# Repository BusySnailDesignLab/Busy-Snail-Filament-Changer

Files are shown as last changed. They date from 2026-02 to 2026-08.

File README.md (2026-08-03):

# Busy Snail Filament Changer<sup>*</sup> (BSFC)

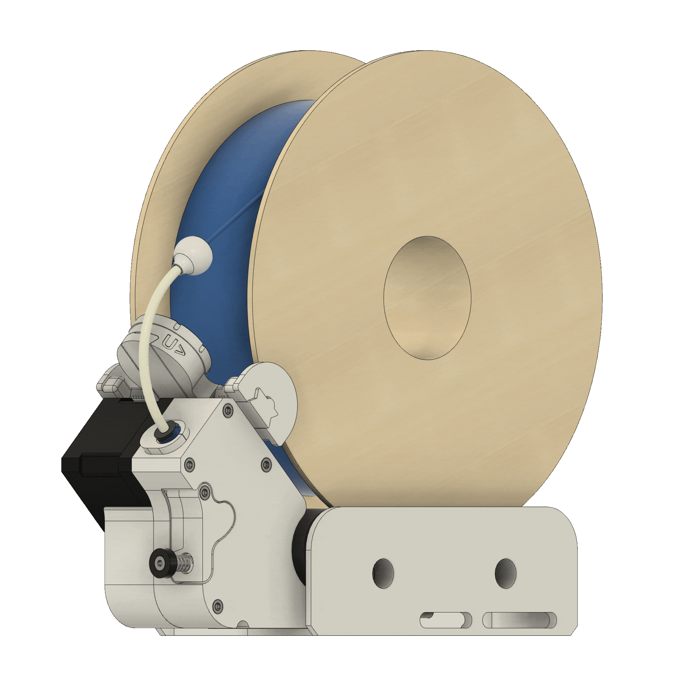
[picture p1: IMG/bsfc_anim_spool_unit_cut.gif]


## One More Filament Changer Design?

The main starting point for the project was originally my tall Voron printer (400x400x800mm) and its almost 3000mm filament path. Moving three meters of filament in a PTFE tube with a few bends causes quite a bit of friction and challenges. I also wanted the option to use 5kg filament spools. Couldn't find an existing solution that was exactly what I had in mind, and down the rabbit hole I went.

Features that were targeted in the design process:

- Support for larger than 1kg spools up to 5kg
- Large extruder gears to maximize filament traction
- NEMA17 stepper motors for power and speed
- Extruder and spool rewind function operated per spool unit by the same stepper motor
- Option to build and use only one spool unit as a loader/unloader/assisting extruder rather than a changer
- As modular system as possible where components are connected to each other by threaded rods
- Keeping the BOM as light as possible with fairly easily accessible items

<br/>

<p align="left">
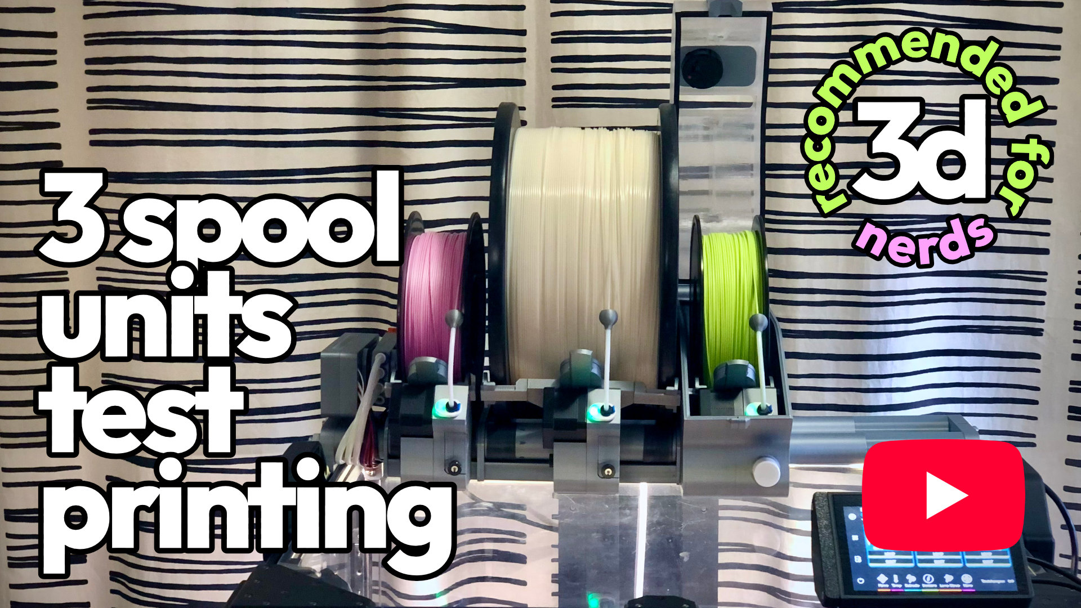
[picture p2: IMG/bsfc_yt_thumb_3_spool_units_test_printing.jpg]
  
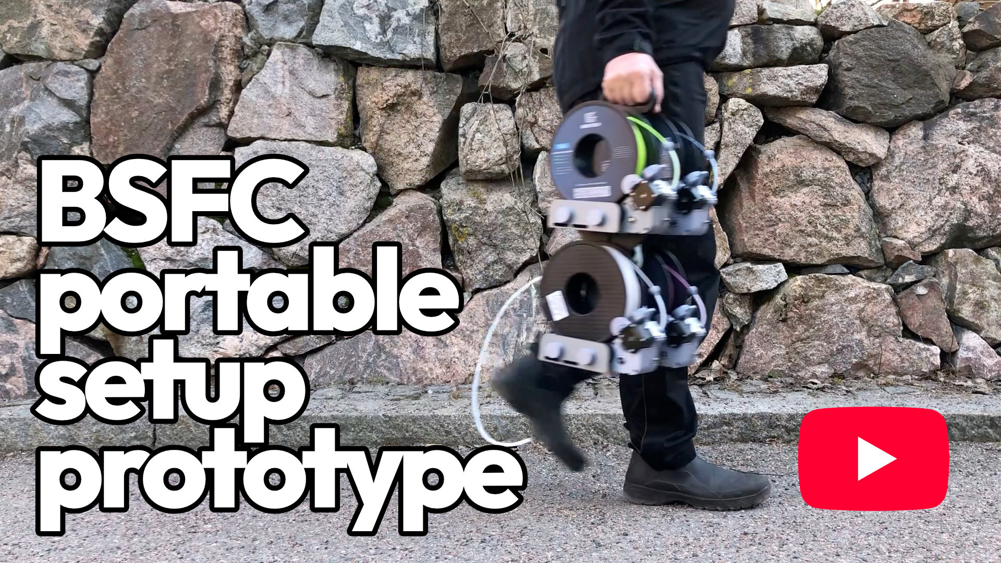
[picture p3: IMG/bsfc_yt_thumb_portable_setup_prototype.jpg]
  
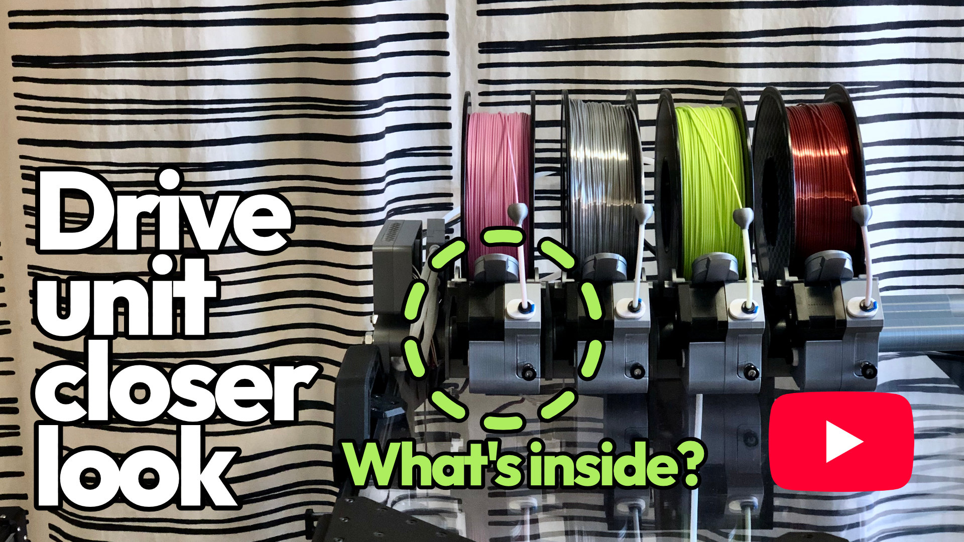
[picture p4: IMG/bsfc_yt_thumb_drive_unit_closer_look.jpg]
  
</p>

[YouTube playlist](https://www.youtube.com/playlist?list=PLjJb97KCYTC8oeRxWj5jBiS8WIRQJnpdh) of all BSFC prototyping and testing videos.

<br/>

<sub> *Different manufacturers have been creative in their naming and wrapping the same function in their own distinct corporate marketing. Prusa kicked off the trend with the MMU (Multi Material Unit), which was followed by Bambu Lab’s AMS (Automatic Material System) and Creality’s CFS (Creality Filament System). Meanwhile, Bigtreetech launched the ViViD (Multi-color Filament Management System), Elegoo went in an abstract direction with the Canvas, and Qidi Tech opted for the Qidi Box. And the list goes on. — But Busy Snail Filament Changer just changes filament, and nothing more. </sub>

<br/>

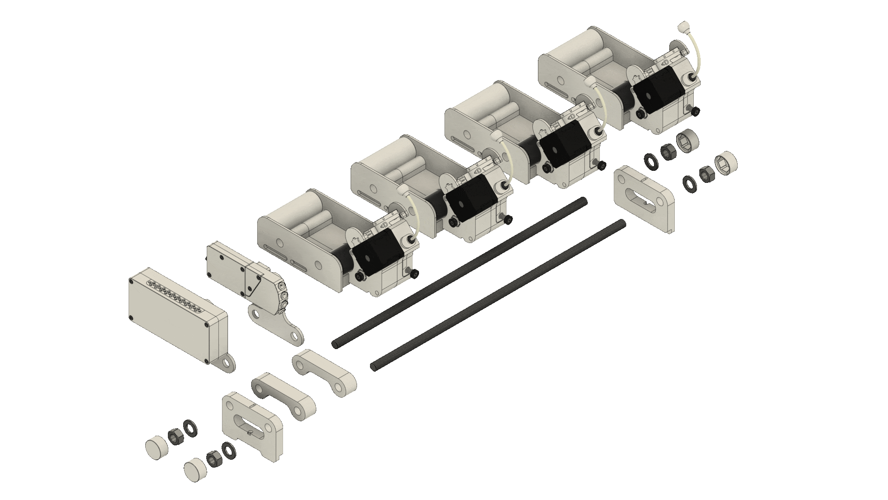
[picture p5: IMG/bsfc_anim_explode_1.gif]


<br/>

## Public Beta 2026.06

The Busy Snail Filament Changer is transitioning from closed testing to the wider community in June 2026. This public beta release represents what should be the final design. The core architecture is locked, though minor adjustments may still occur.

<br/>

## 3d-files and Printing

The files considered as a basic setup are available in this root directory, everything else can be found in the MODs folder.
Provided STL files are in their intended printing orientation, supports and some bed adhesion helpers are modeled in the files. Also, some STEP files of assemblies are provided to allow one to adjust or modify if wished.

Prototyping was done using PLA and PETG filaments. There are some areas in some of the parts with some fairly thin walls where using ABS might be challenging due to its generally poorer layer adhesion. (eSun ABS+ philosophy: strong odor - weak layer adhesion...) Even though we are being spoiled with more and more fancy new filaments these days, and there are surely good candidates among them, this application is probably not demanding enough to justify using anything too fancy.

As is usually the case with projects of this nature, the 3D printer itself and slicer profiles must be properly calibrated. The clearances of the printed parts have been designed and tested based on this assumption.

[Ellis' Print Tuning Guide](https://ellis3dp.com) is naturally the place to go when things don't fit together.

<details>
<summary>Some printing parameters used in the design and prototyping process</summary>

### Most of the parts:

Generic settings have been found to be sufficiently robust in the basic parts.
- 0.4mm nozzle/extrusion width
- 0.2mm layer height
- 0.2mm first layer height
- 3 perimeters
- 5 top, 4 bottom solid layers
- 25% infill
- 0.25mm elephant foot compensation
- No supports

### Geartrain and clutch:
(_rewind_geartrain, _clutch_gear)

Higher perimeter count and infill density to beef up a little bit.
- 0.4mm nozzle/extrusion width
- 0.2mm layer height
- 0.2mm first layer height
- 5 perimeters
- 5 top, 4 bottom solid layers
- 50% infill
- 0.25mm elephant foot compensation
- No supports

### Roller trays, spool rollers and frame spacers:
(_tray_main_left, _tray_main_right, _roller_front, _roller_rear, _spacer_scale_to_length_in_slicer)

Larger 0.6mm nozzle to speed up printing of these dimensionally less critical larger parts.
- 0.6mm nozzle/extrusion width
- 0.3mm layer height
- 0.3mm first layer height
- 3 perimeters
- 4 top, 3 bottom solid layers
- 15% infill
- 0.25mm elephant foot compensation
- No supports

</details>

<br/>

## Technical Details and Build

This section contains illustrations and descriptions of BSFC and its subcomponents and functions to support the building process. Each subsection contains also a link to the corresponding tutorial video on YouTube.

Slight differences may exist between the printed parts shown in the illustrations or videos and the current STLs, as development continued during and after content creation.

<details>
<summary>Rewind clutch</summary>

<br/>

The rewind clutch is closely related to the traditional freecoaster rear hub used on BMX bicycles.
<br/>

When the stepper motor rotates in the feed/extrude direction, the clutch disengages; the clutch gear freewheels, allowing the spool rewind roller to rotate freely. In the rewind/retract direction, the clutch engages and the spool is rewound.
<br/>

The friction of the spring-loaded conical interface must be greater than the friction of the engager component's steep thread. The spring should not be adjusted too tight; however, an adjustment that is too loose will prevent the clutch from operating.
<br/>

For the clutch to function properly, a small amount of silicone grease must be applied to its contact surfaces.
<br/>

[Assembly video](https://youtu.be/TbNA-HyEh_M?si=HdrPlAlg6tBJTh0d) on YouTube.

<br/>

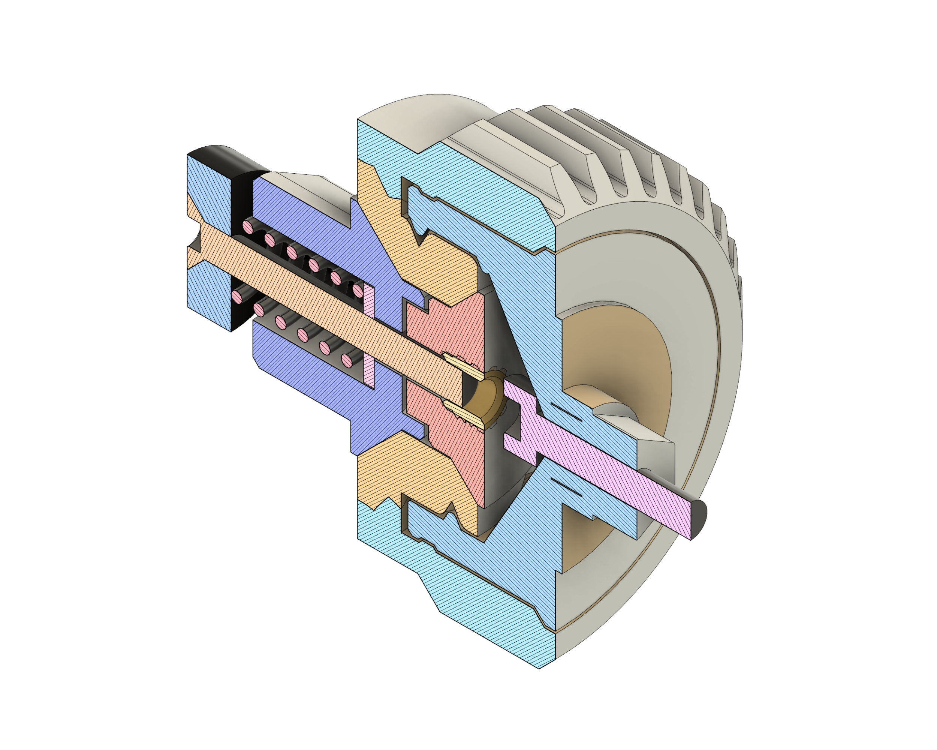
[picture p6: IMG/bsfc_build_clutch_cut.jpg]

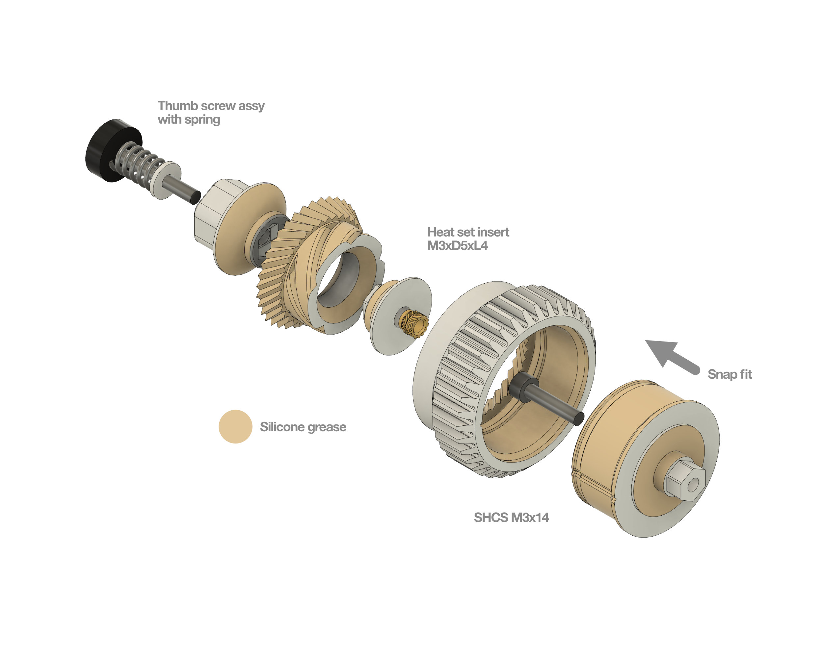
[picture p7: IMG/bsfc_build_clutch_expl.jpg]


</details>

<details>
<summary>Spool controller</summary>

<br/>

Since the extruder and rewind gear train have a fixed gear ratio, the system is optimized for nearly empty spools to ensure sufficient rewind tension. Because of this, a fuller spool naturally has a higher peripheral velocity than an emptier one, meaning some slippage must occur between the roller and the spool. When the spool attempts to move faster than the retracted filament allows, it climbs against the spool controller and slips slightly, resulting in a constant "micro-jumping" effect.
<br/>

The chosen approach was to maximize the grip between the roller and the spool using a butyl rubber inner tube, then manage the necessary slippage through the spool controller. This method proved to be the only viable solution, as the grip of a full 5kg spool on the roller is exceptionally strong vs almost empty 1kg spool.
<br/>

The height of the spool controller is adjusted by rotating the thumbwheel, which stays in position due to the worm gear construction. If the controller is set too low, the spool will slip excessively and fail to rewind properly. Conversely, if it is set too high, the jumping motion becomes too aggressive. Fortunately, the optimal adjustment has a fairly large tolerance for the rewind function to work reliably.
<br/>

[Assembly video](https://youtu.be/K6IZ9RyGhMk?si=yHqPg5wZYAanlQJ6) on YouTube.

<br/>

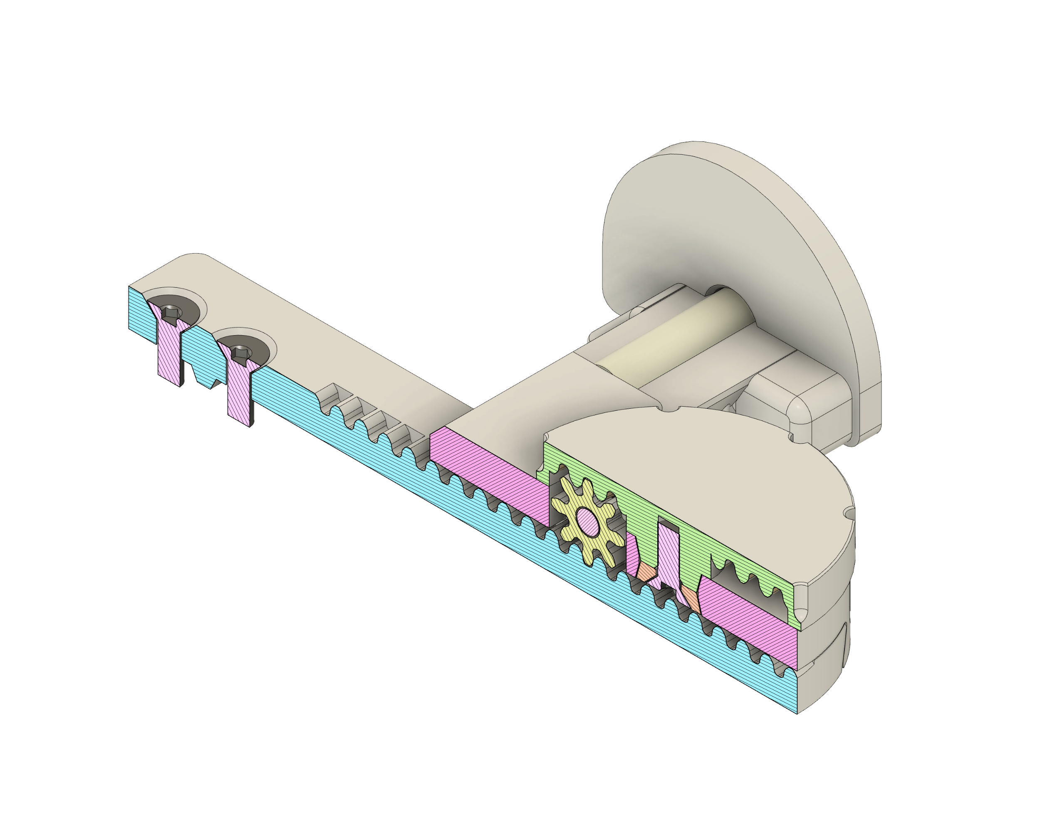
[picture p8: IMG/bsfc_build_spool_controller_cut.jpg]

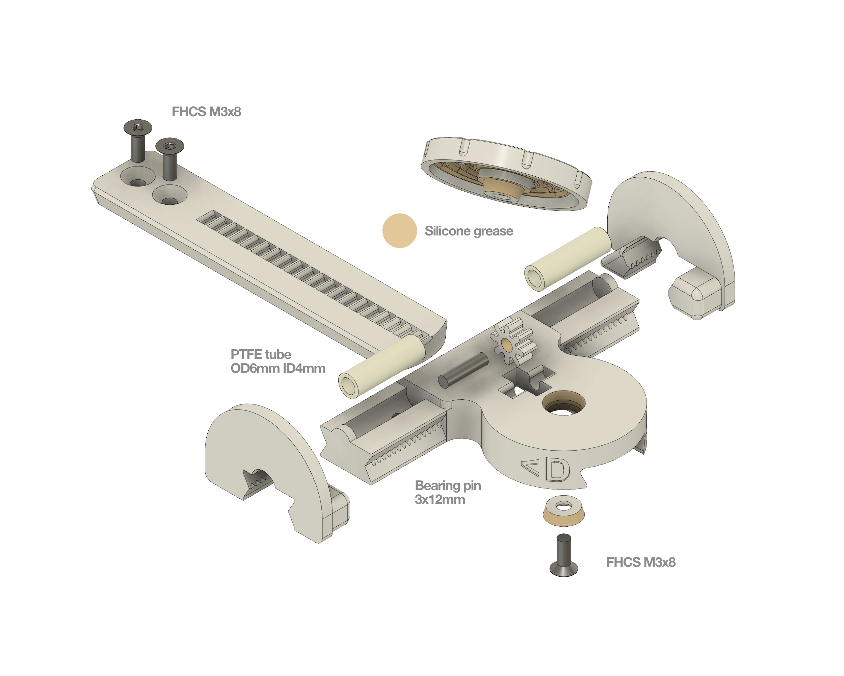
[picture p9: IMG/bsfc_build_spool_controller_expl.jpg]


</details>

<details>
<summary>Drive unit</summary>

<br/>

The drive unit is in a way divided into two functional sections: motor/rewind and extruder section.
<br/>

[Assembly video](https://youtu.be/VoX7NNussHw?si=F9h9A9wVGLavogpF) on YouTube.

<br/>

Whole unit
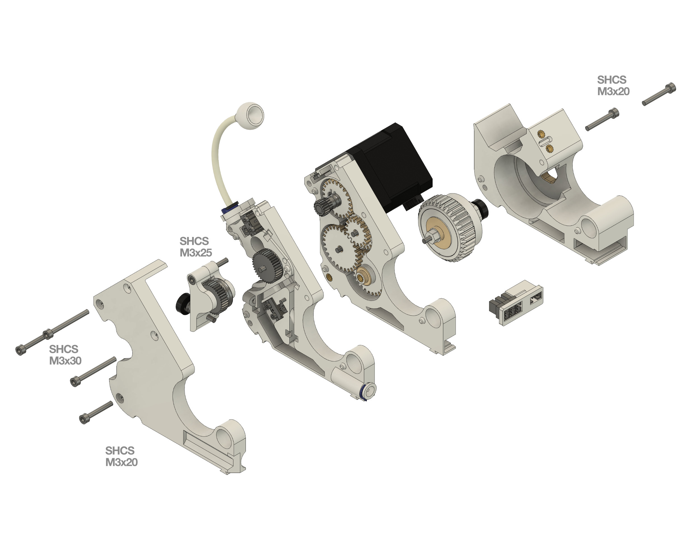
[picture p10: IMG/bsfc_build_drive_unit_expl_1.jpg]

Motor/rewind section
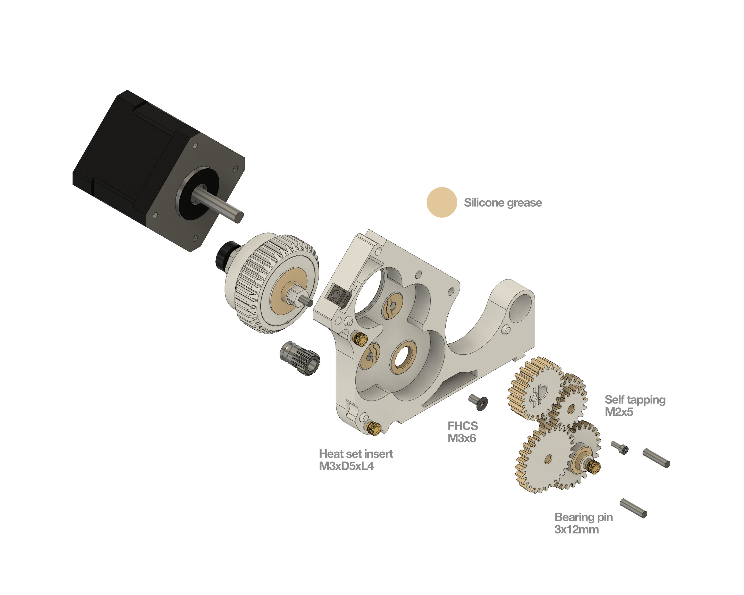
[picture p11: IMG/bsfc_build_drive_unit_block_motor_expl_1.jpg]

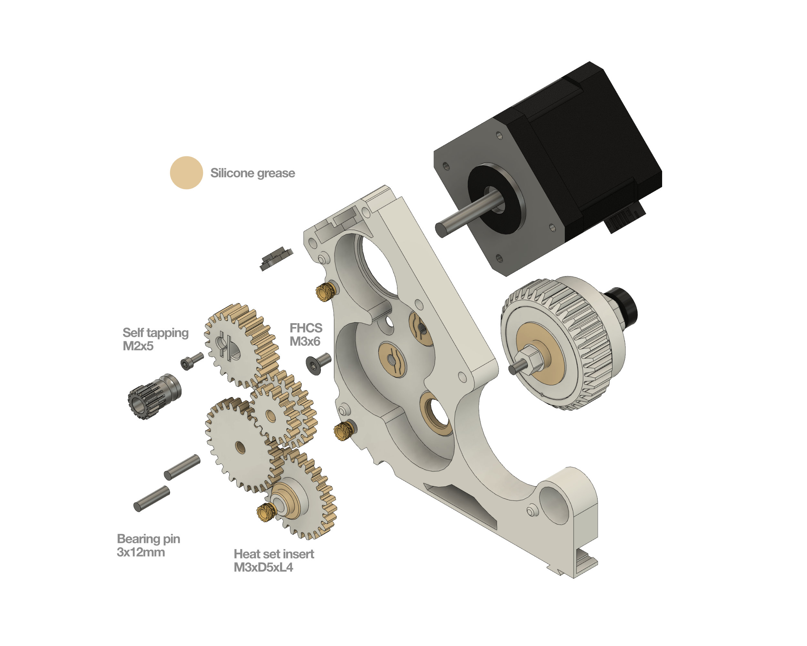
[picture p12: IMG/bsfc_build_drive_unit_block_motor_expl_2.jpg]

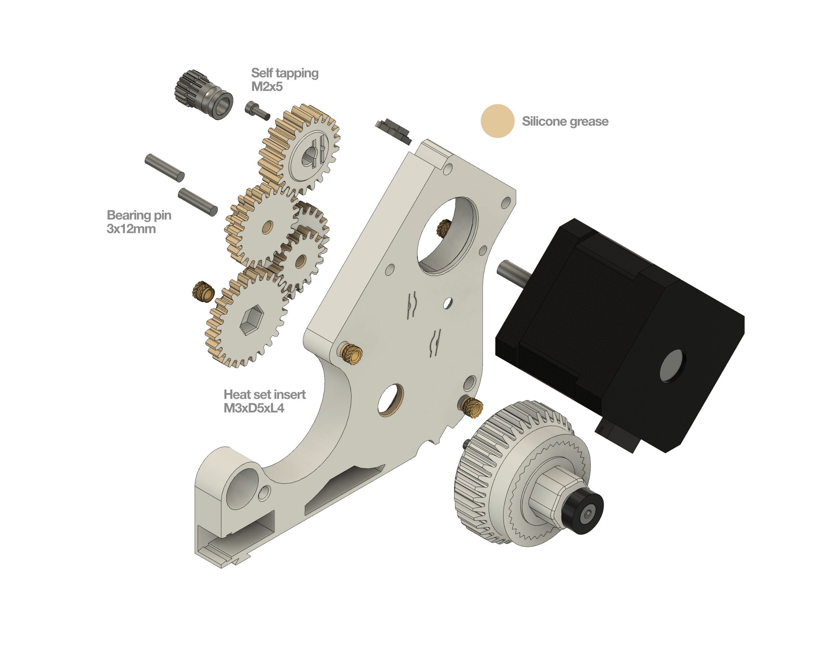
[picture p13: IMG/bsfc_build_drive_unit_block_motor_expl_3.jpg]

Extruder section
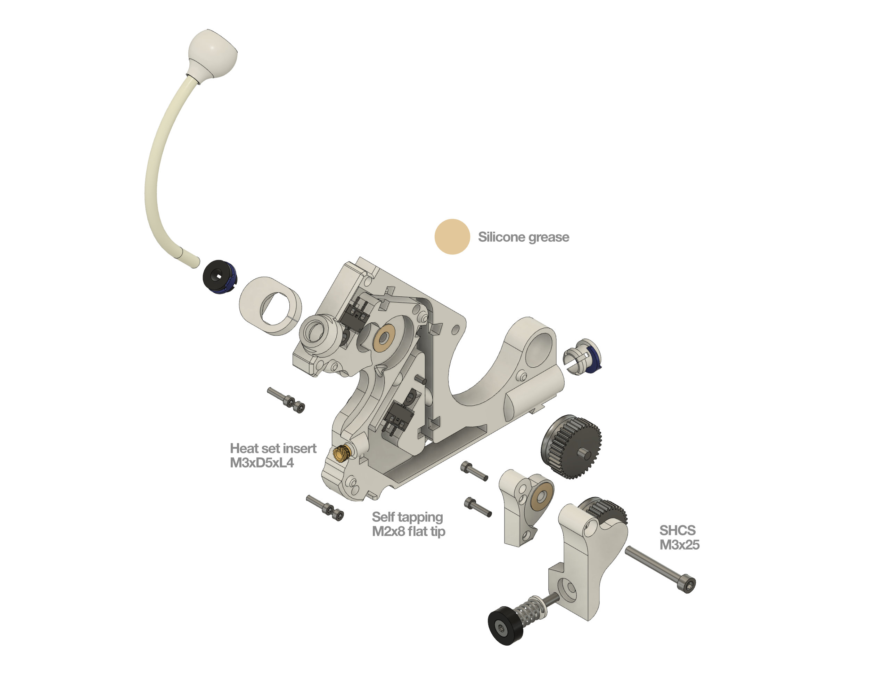
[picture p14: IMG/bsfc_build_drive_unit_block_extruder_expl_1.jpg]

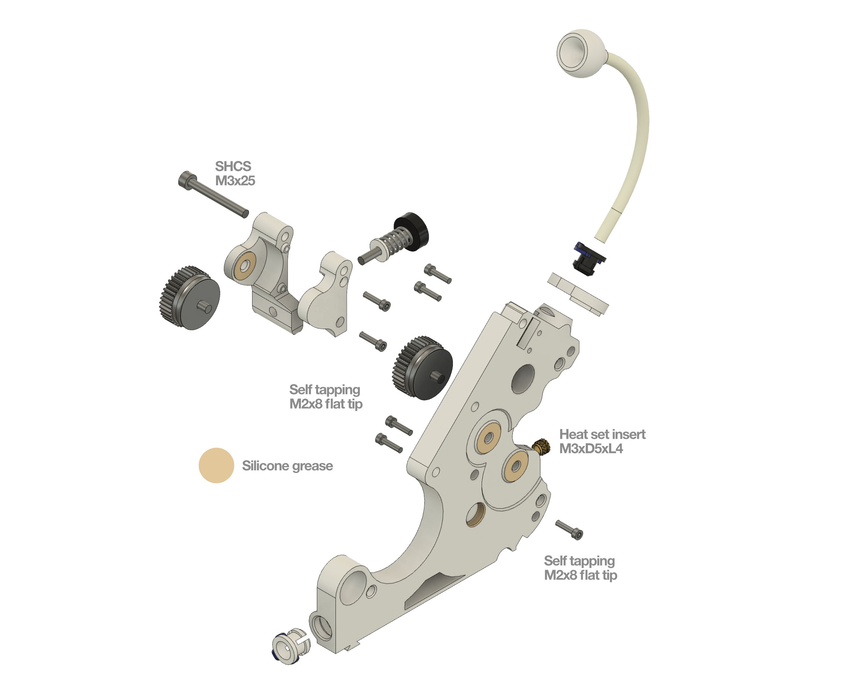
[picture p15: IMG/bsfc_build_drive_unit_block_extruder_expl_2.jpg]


</details>

<details>
<summary>Roller tray</summary>

<br/>

[Assembly video](https://youtu.be/v3EZafkdpoI?si=Pa8eA2tnM2RYGXaa) on YouTube.

<br/>
 
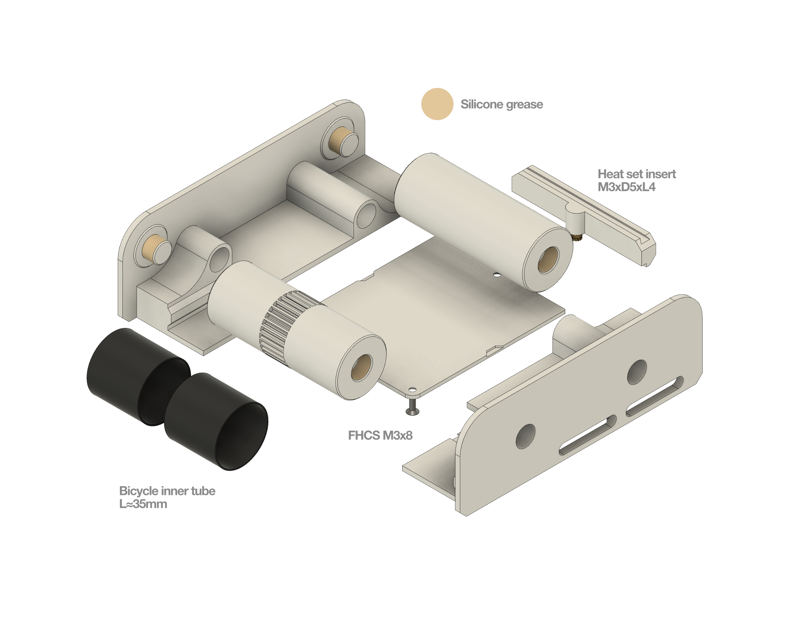
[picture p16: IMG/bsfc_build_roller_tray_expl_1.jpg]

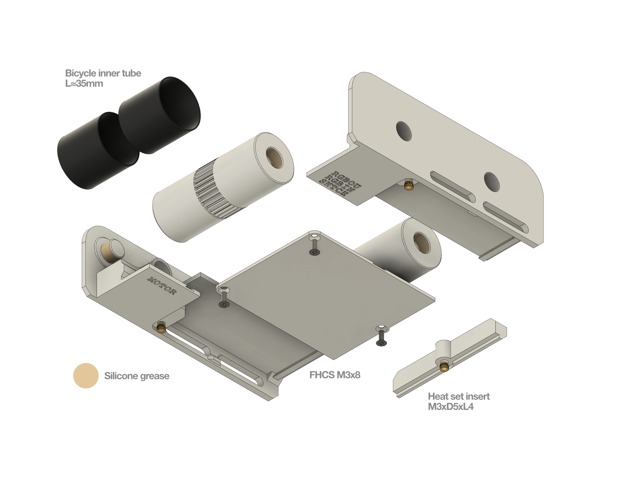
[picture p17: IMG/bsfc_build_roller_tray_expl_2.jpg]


</details>

<details>
<summary>Hub-buffer</summary>

<br/>

[Assembly video](https://youtu.be/KklAEr8crc0?si=6_zTUBbSNkeF0NI5) on YouTube.

<br/>
 
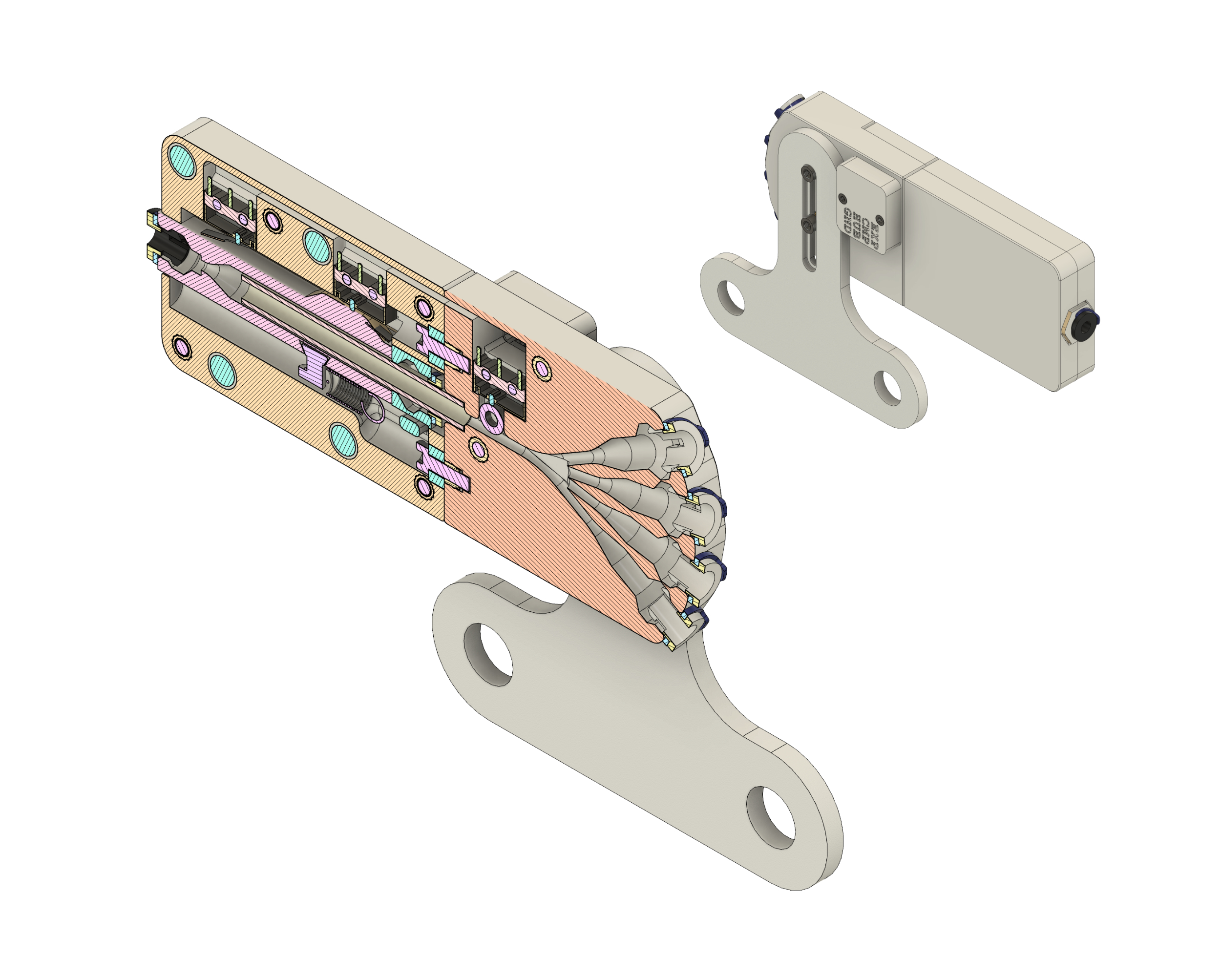
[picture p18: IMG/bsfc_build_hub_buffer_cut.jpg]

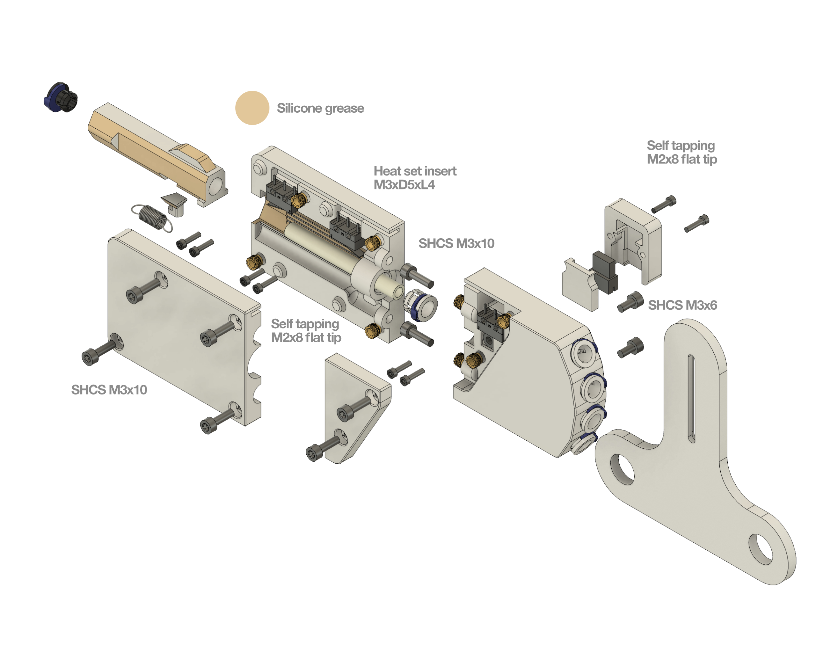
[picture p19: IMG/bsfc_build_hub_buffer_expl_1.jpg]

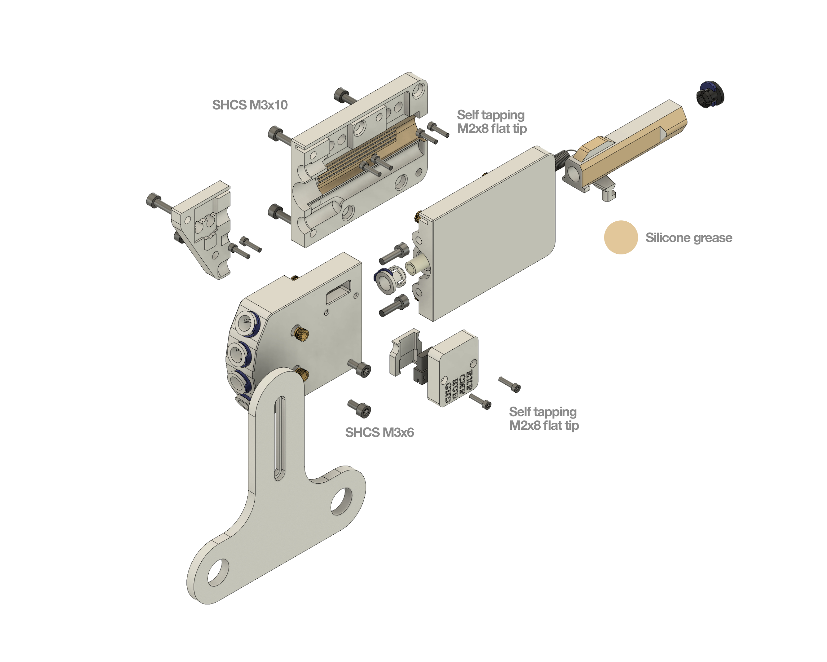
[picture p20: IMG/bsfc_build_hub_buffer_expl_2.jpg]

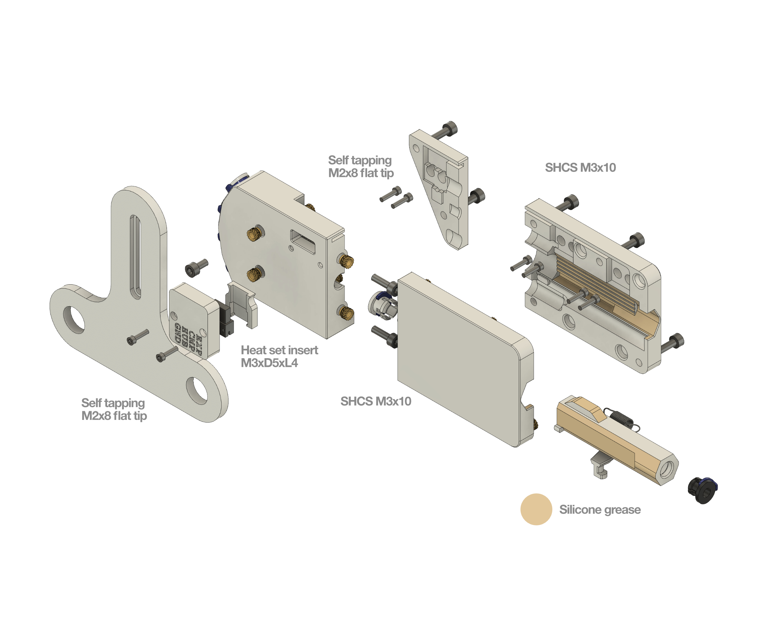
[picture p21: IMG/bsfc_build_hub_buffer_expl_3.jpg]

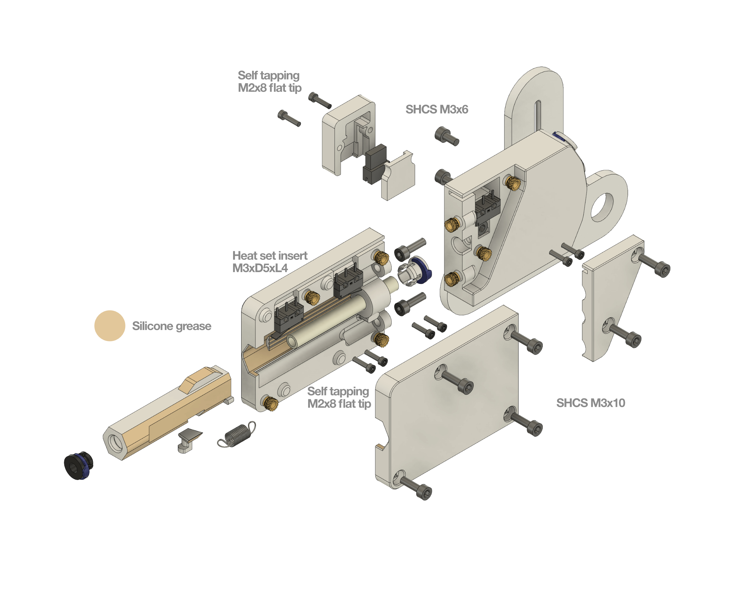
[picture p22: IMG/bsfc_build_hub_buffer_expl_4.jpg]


</details>

<details>
<summary>Control board box</summary>
	
<br/>

The control board box currently supports Bigtreetech MMB CAN V1 and V2 boards. The box is sized to accommodate both board versions, with each having its own dedicated mounting bracket.
<br/>

[Assembly video](https://youtu.be/oLnCz8qqsjE?si=0IGYUk-QMdZsbvs8) on YouTube.

<br/>

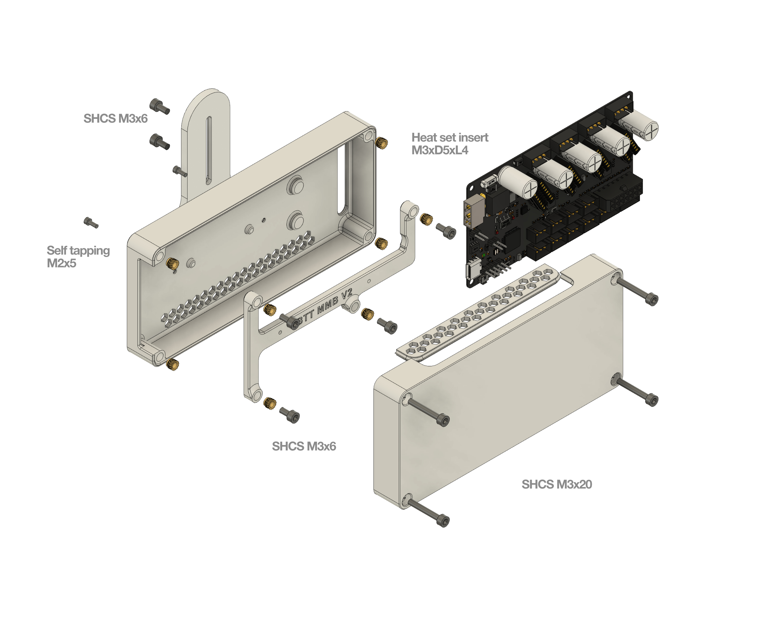
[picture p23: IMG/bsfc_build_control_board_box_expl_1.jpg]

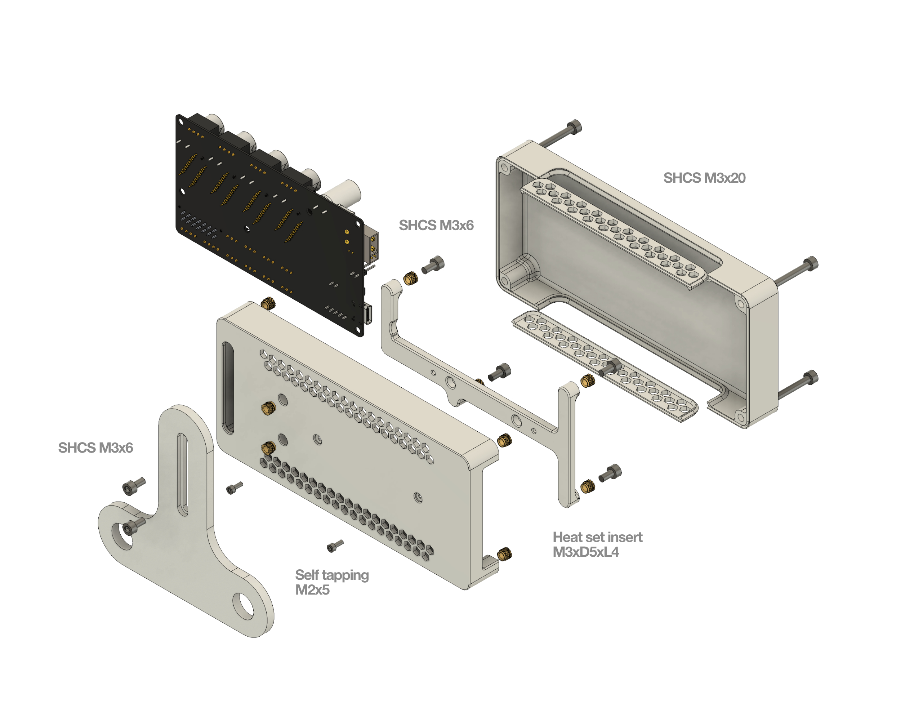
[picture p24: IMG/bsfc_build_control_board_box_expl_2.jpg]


</details>

<details>
<summary>General assembly</summary>
	
<br/>

The finished device consists of components connected by threaded rods.<br/>

<br/>

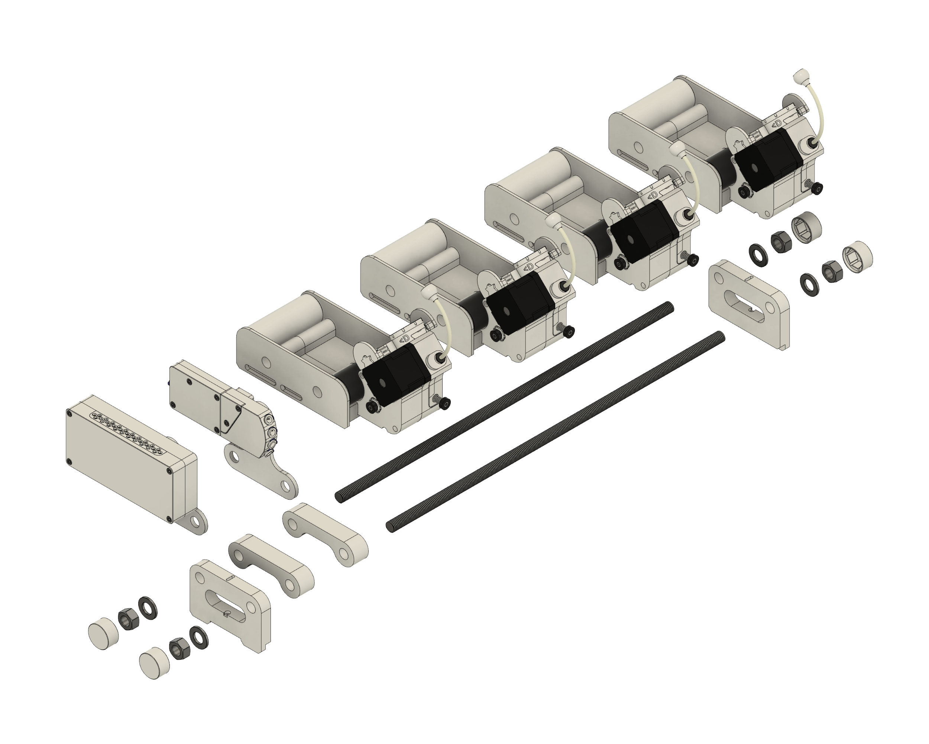
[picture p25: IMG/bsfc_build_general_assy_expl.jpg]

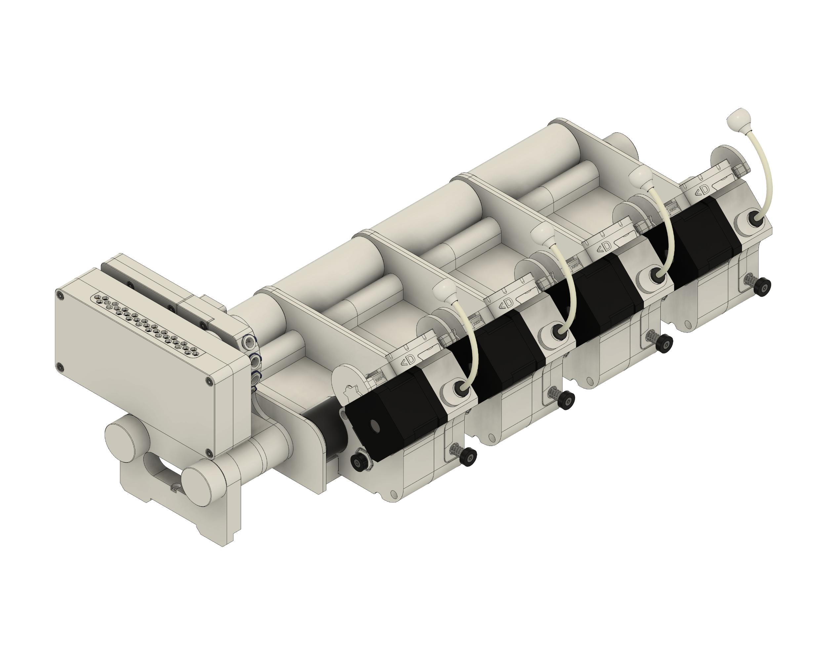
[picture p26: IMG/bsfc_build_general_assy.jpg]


</details>

[YouTube playlist](https://www.youtube.com/playlist?list=PLjJb97KCYTC9PMECO4NPdOToGcQD9c51B) of current BSFC tutorial videos.

<br/>

## Software Configuration

Work in progress. <br/>
BSFC prototyping was done using [AFC-Klipper-Add-On](https://github.com/ArmoredTurtle/AFC-Klipper-Add-On) and using its [documentation](https://www.armoredturtle.xyz/docs/afc-klipper-add-on/index.html) to set things up. Compatibility with [Happy-Hare](https://github.com/moggieuk/Happy-Hare) has not yet been tested.

<details>
<summary>Some AFC-Klipper-Add-On config settings</summary>

<br/>

These settings instead of the default values were used in .cfg files when prototyping BSFC:

- rotation_distance: 24.84
- run_current: 1.7

<br/>

- long_moves_speed: 300
- long_moves_accel: 150
- short_moves_accel: 150
- global_print_current: 0.8

<br/>

Pin mappings for Bigtreetech mmb can v1.1 control board:

/config/AFC/mcu/MMB_1.1.cfg

```
[board_pins Your_Unit_Name]
mcu: Your_Mcu_Name
aliases:
    M1_STEP=PB15   , M1_DIR=PB14   , M1_EN=PB8    , M1_UART=PA10   ,
    M2_STEP=PD2    , M2_DIR=PB13   , M2_EN=PD1    , M2_UART=PC7    ,
    M3_STEP=PD0    , M3_DIR=PD3    , M3_EN=PA15   , M3_UART=PC6    ,
    M4_STEP=PB6    , M4_DIR=PB7    , M4_EN=PB5    , M4_UART=PA9    ,

	HUB=PB11 		, 
	TRG1=PA3  		, TRG2=PA4  	, TRG3=PB9 		, TRG4=PA8		,
	EXT1=PC15 		, EXT2=PC13		, EXT3=PC14		, EXT4=PB12		,
    TN_ADV=PB10     , TN_TRL=PB2 ,
	RGB1=PA2		, 
```

Pin mappings for Bigtreetech mmb can v2.0 control board:

/config/AFC/mcu/MMB_2.0.cfg

```
[board_pins Your_Unit_Name]
mcu: Your_Mcu_Name
aliases:
    M1_STEP=PD4    , M1_DIR=PD3    , M1_EN=PD5    , M1_UART=PB5    ,
    M2_STEP=PC9    , M2_DIR=PC8    , M2_EN=PD2    , M2_UART=PB4    ,
    M3_STEP=PC15   , M3_DIR=PC11   , M3_EN=PC10   , M3_UART=PB3    ,
    M4_STEP=PC13   , M4_DIR=PC12   , M4_EN=PC14   , M4_UART=PD6    ,

	HUB=PA15 		, 
	TRG1=PC5  		, TRG2=PB1  	, TRG3=PB10		, TRG4=PB12 	,
	EXT1=PC4  		, EXT2=PB0 		, EXT3=PB2 		, EXT4=PB11		,
    TN_ADV=PA10     , TN_TRL=PD9 ,
	RGB1=PC3		, 
```

</details>

<br/>

## Financial Aspects

When you do something as a hobby, it’s pure fun. The hours don’t matter because there are always too few—you know that feeling when you completely lose track of time? But what about the expenses? Well, who on earth would remember those... 

Yet somehow, in a strange way, those costs tend to add up when prototyping. If you’ve enjoyed or benefited from this project, I would be incredibly grateful for a small contribution to help cover some of the expenses involved.



<br/>

## Bill of Materials Kits <sup>*</sup>

[Mellow](https://3dmellow.com/products/) has expressed interest in offering a BSFC BOM kit. There is no date yet for when it will be available. When it is released, a link will be provided here.

<br/>

<sub> *Busy Snail Design Lab is not affiliated with any of the available BOM kits. Any questions or inquiries regarding the kits should be directed to their respective providers. </sub>

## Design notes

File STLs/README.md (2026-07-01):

# Busy Snail Filament Changer (BSFC) STLs

## Things to Consider
- Parts that attach to threaded rods are M12 (12.15mm hole size) by default. Subfolders contain 1/2"-13 UNC versions (12.9mm hole size).

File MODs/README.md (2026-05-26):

# Busy Snail Filament Changer (BSFC) MODs

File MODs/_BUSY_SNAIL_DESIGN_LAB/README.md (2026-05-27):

# Busy Snail Filament Changer (BSFC) MODs by Busy Snail Design Lab

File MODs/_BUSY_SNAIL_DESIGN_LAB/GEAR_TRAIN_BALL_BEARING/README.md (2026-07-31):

# Busy Snail Filament Changer (BSFC) Drive Unit <ins> Rewind Geartrain Ball Bearing Mod </ins> by Busy Snail Design Lab

Possibly a completely useless mod that only extends the BOM. Rotating polymer parts lubricated with silicone grease are a widely used solution in low speed, light load applications like this. Ball bearings might make this a little quieter. However, high quality ball bearings are quite expensive, some of the cheapest ones on Ali even lack grease inside.

The two drive unit blocks and two gears shown in the pictures are different from the standard ones. A few drops of superglue will help hold the flanged F6700zz bearing in place.

## Additional BOM for one unit

| Item | Qty | Info | Used in prototype 2025 |
|:---|:---:|---|:---|
| Ball bearing MR63zz | 4 | 3x6x2.5mm standard ball bearing | [BEARING](https://www.aliexpress.com/item/1005006266847105.html) |
| Ball bearing MR117zz | 1 | 7x11x3mm standard ball bearing | [BEARING](https://www.aliexpress.com/item/1005005989209583.html) |
| Ball bearing F6700zz | 1 | 10x15x4mm flanged ball bearing | [BEARING](https://www.aliexpress.com/item/1005006018219987.html) |

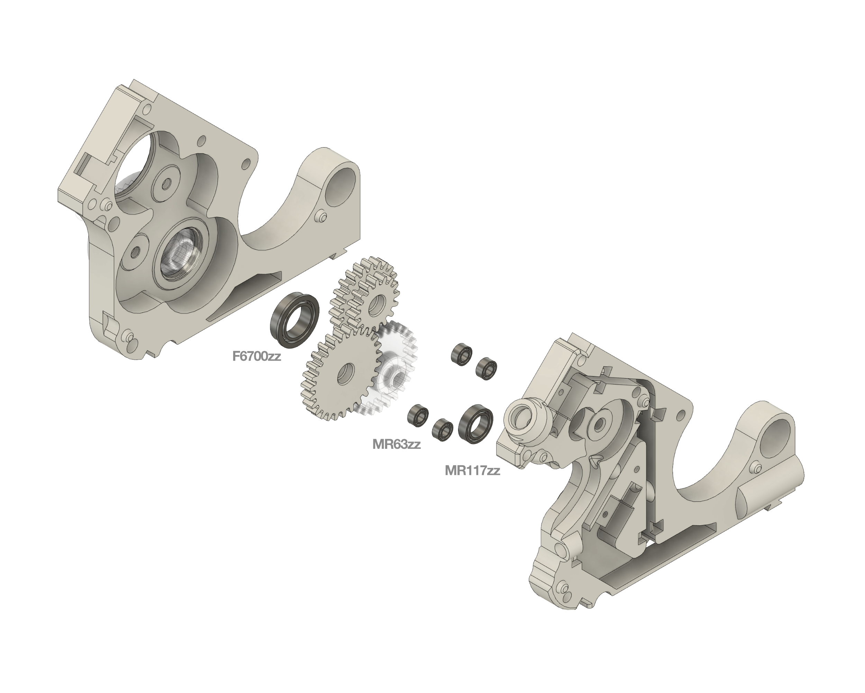
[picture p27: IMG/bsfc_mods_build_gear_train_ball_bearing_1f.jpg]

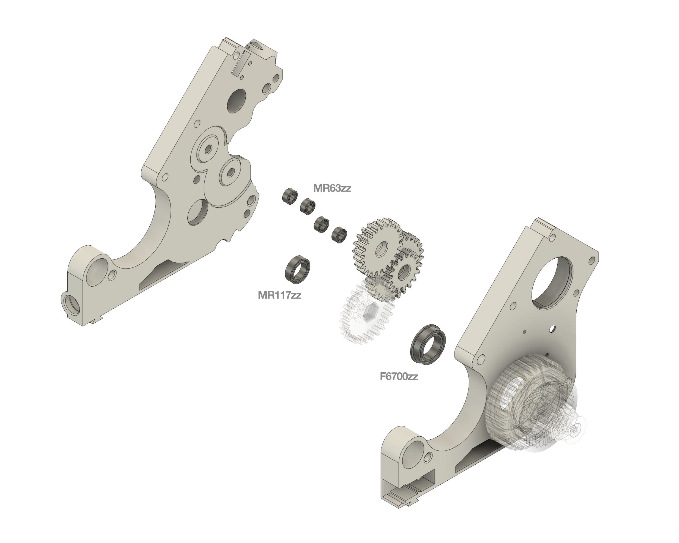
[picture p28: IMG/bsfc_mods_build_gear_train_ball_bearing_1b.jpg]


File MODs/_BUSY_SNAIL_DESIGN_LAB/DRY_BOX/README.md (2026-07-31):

# Busy Snail Filament Changer (BSFC) <ins> Dry Box Mod </ins> by Busy Snail Design Lab

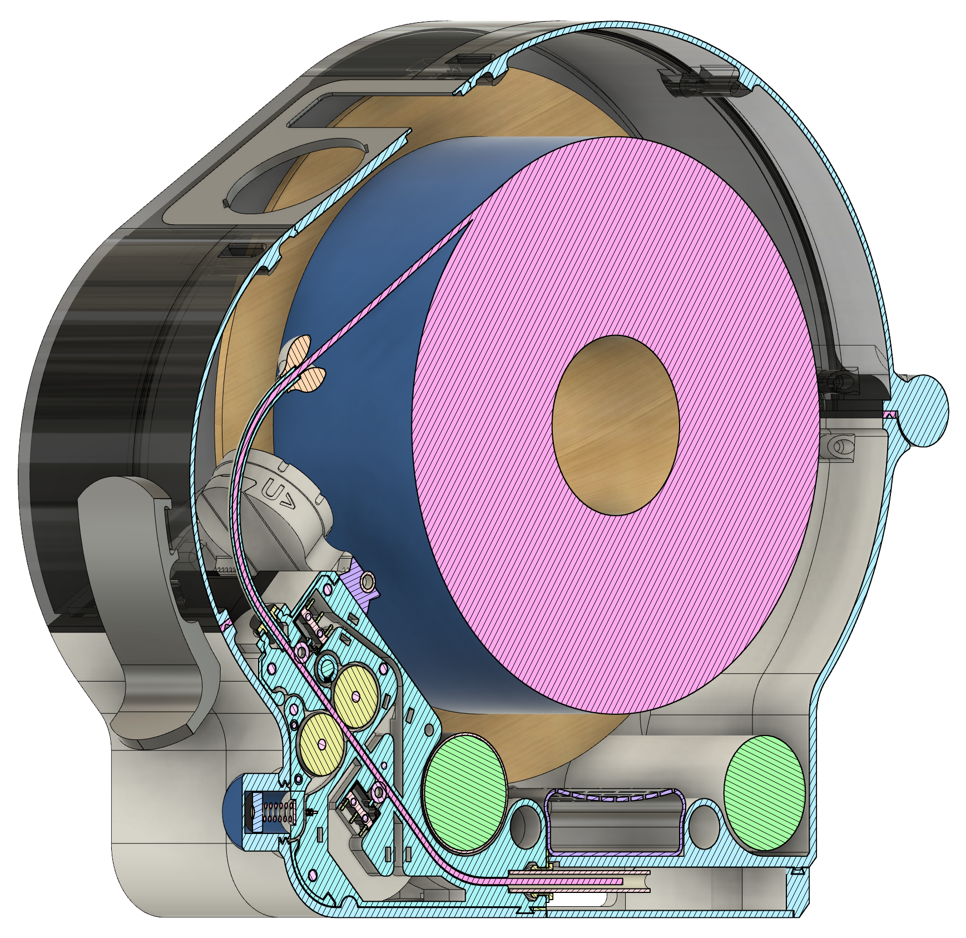
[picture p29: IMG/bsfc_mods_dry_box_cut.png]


## Additional BOM for one unit

| Item | Qty | Info | Used in prototype 2025 |
|:---|:---:|---|:---|
| Self tapping screw M2x10 | 9 | | |
| Sealing foam tape 5x3mm | ≈0.74m | Self adhesive foam sealing tape width 5mm thickness 3mm | [FOAM TAPE](https://www.aliexpress.com/item/1005009421064177.html) |
| Sealing foam tape 5x1mm | ≈0.14m | Self adhesive foam sealing tape width 5mm thickness 1mm | [FOAM TAPE](https://www.aliexpress.com/item/1005009421064177.html) |
| (Plastic sheet 1mm) | (1) | Optional window, 1mm thick cuts with scissors | [PLASTIC SHEET](https://www.aliexpress.com/item/1005009018470808.html) |
| (Hygrometer) | (1) | Optional hygrometer, STL supports round type | [HYGROMETER](https://www.aliexpress.com/item/1005010810953947.html) |
| (Clear silicone sealant) | | | [SILICONE SEALANT](https://www.aliexpress.com/item/1005011587238661.html) |

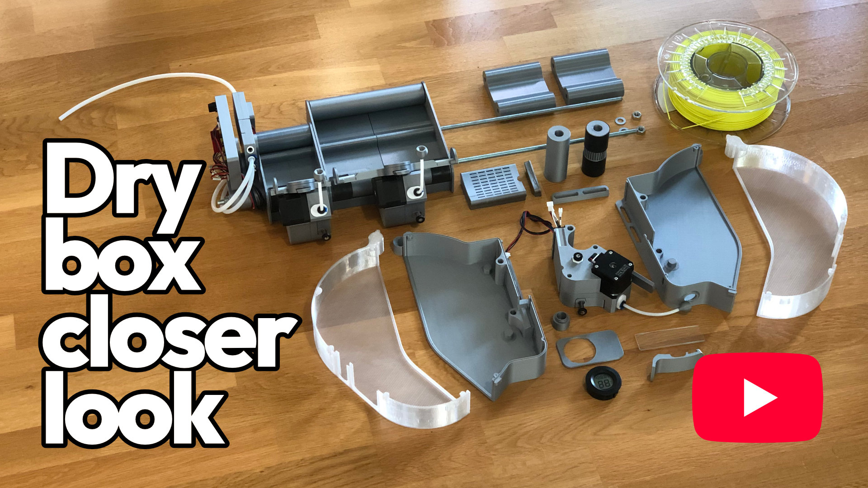
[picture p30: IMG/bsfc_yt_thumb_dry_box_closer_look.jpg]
(https://youtu.be/eBFVZCE4isA)

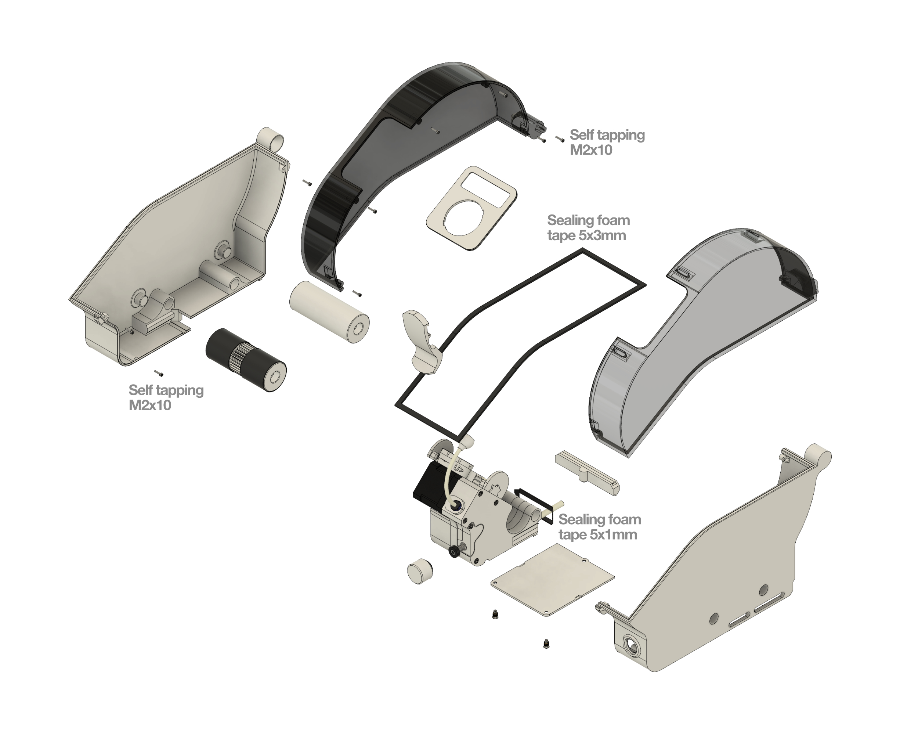
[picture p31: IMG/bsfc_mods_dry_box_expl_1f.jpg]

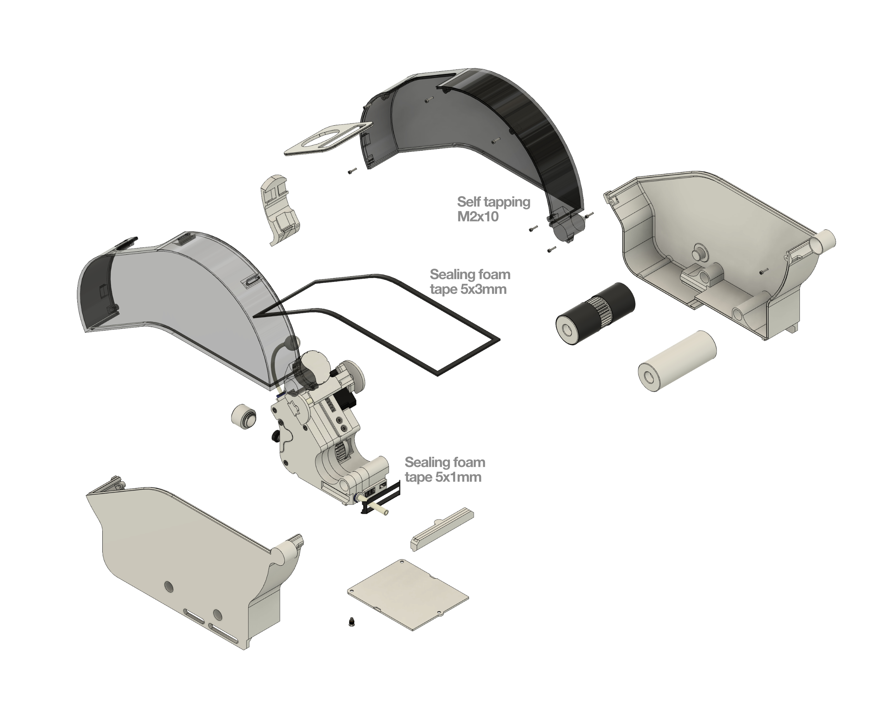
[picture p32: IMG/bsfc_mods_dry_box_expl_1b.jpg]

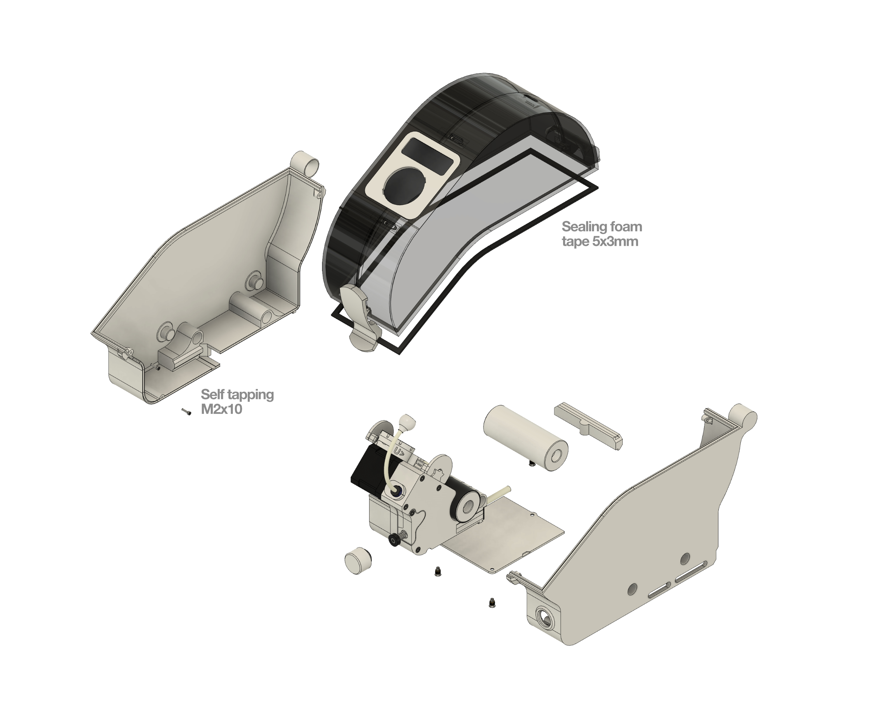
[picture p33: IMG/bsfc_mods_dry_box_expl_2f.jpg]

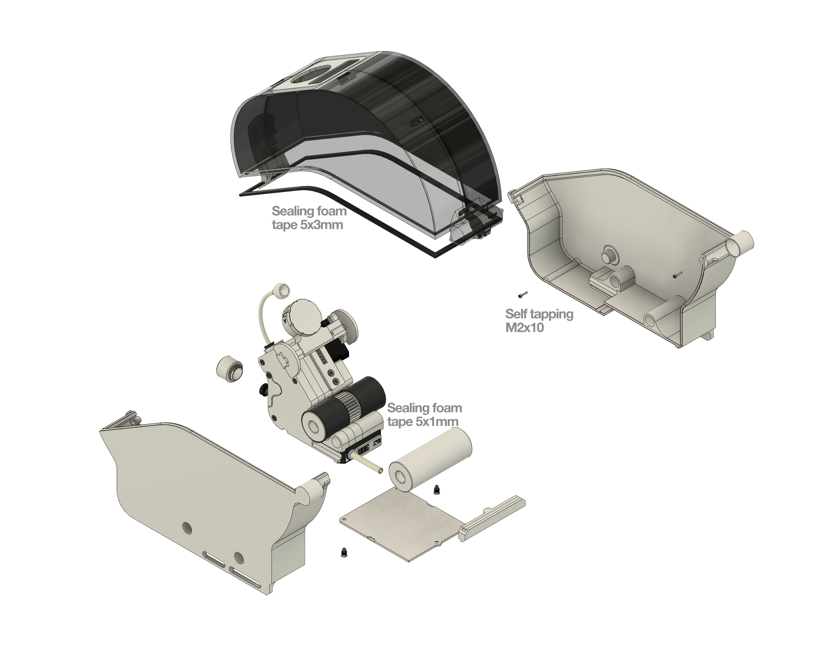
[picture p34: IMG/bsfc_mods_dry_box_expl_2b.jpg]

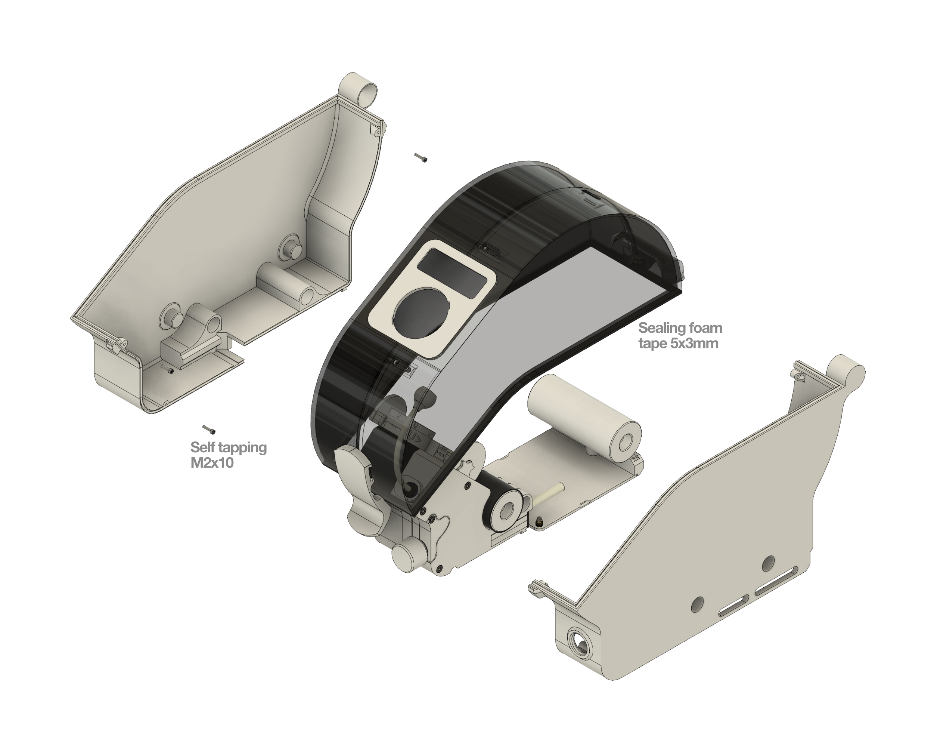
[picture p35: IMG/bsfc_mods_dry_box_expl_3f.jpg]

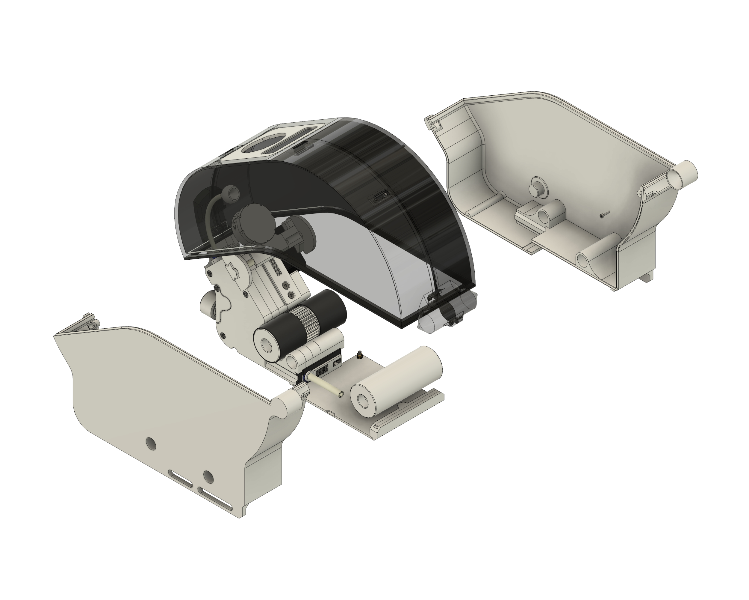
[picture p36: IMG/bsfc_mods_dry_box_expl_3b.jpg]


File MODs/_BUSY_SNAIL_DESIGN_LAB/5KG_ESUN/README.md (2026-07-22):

# Busy Snail Filament Changer (BSFC) Roller Tray And Spool Controller for eSun <ins> 5kg Spool Mod </ins> by Busy Snail Design Lab
This mod has been tested and used with the eSun 5kg spool (d=300mm, w=160mm). It should also work with other brands using this standard off-the-shelf spool size, though this has not been confirmed.

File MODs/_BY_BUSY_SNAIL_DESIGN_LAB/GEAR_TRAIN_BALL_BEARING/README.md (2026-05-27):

# Busy Snail Filament Changer (BSFC) Drive Unit Rewind Geartrain Ball Bearing Mod by Busy Snail Design Lab
# COMING SOON (TM)

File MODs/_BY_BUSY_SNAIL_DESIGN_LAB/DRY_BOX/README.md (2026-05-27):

# Busy Snail Filament Changer (BSFC) Dry Box Mod by Busy Snail Design Lab
# COMING SOON (TM)

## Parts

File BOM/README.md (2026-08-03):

# Busy Snail Filament Changer (BSFC) BOM

For a 4x1kg spool units changer totals by item groups see [PDF](https://github.com/BusySnailDesignLab/Busy-Snail-Filament-Changer/blob/main/BOM/BSFC_BOM_4x1kg_totals_V2026-02-04.pdf).

<br/>
<br/>

bom_drive_unit_no_sc

## DRIVE UNIT (4x for 4 spool changer)

| Image # | Item | Qty | Info | Used in prototype 2025 |
|:---:|:---|:---:|---|:---|
| DU01 | Heat set insert M3xD5xL4 | 9 | Same as Voron BOM size | |
| DU02 | FHCS M3x6 | 1 | | |
| DU03 | SHCS M3x14 | 1 | | |
| DU04 | SHCS M3x20 | 3 | | |
| DU05 | SHCS M3x25 | 1 | | |
| DU06 | SHCS M3x30 | 3 | | |
| DU07 | Self tapping screw M2x5 | 1 | Or cut longer screw to 5mm (<6mm) thread length, longer interferes the stepper motor collar | |
| DU08 | Self tapping M2x8 flat tip  | 7 | At least 4pcs must be flat tip for micro switches (limited threading depth avail. in the part) | [SELF TAPPING FLAT TIP](https://www.aliexpress.com/item/1005008143160245.html) |
| DU09 | BMG 17 teeth extruder gear  | 1 | Extruder drive gear with grub screw for 5mm stepper shaft | [BMG-17 GEAR](https://www.aliexpress.com/item/32969501213.html) |
| DU10 | Ball bearing MR63zz | 2 | Included in HGX-lite extruder part kits, used as trigger for filament presence switch | [HGX-LITE KIT](https://www.aliexpress.com/item/1005008082439342.html)  |
| DU11 | Large extruder gear | 2 | Included in HGX-lite extruder part kits | [HGX-LITE KIT](https://www.aliexpress.com/item/1005008082439342.html)  |
| DU12 | Needle bearing 3x5x6.5mm | 2 | Included in HGX-lite extruder part kits | [HGX-LITE KIT](https://www.aliexpress.com/item/1005008082439342.html)  |
| DU13 | Thumb screw assy with spring| 2 | 1pc included in HGX-lite extruder part kits, second one is for the rewind clutch | [HGX-LITE KIT](https://www.aliexpress.com/item/1005008082439342.html) / [THUMB SCREW ASSY](https://www.aliexpress.com/item/32947691813.html)|
| DU14 | Bearing pin 3x12mm | 2 | For rewind geartrain | [BEARING PIN](https://www.aliexpress.com/item/33005238671.html) |
| DU15 | Bearing pin 3x16mm | 2 | Included in HGX-lite extruder part kits | [HGX-LITE KIT](https://www.aliexpress.com/item/1005008082439342.html)  |
| DU16 | Tube collet 4mm | 1 | Drive unit filament input | [TUBE COLLET 4mm](https://www.aliexpress.com/item/1005008047671379.html) |
| DU17 | Tube collet 6mm | 1 | Drive unit filament output | [TUBE COLLET 6mm](https://www.aliexpress.com/item/1005007086985966.html) |
| DU18 | PTFE tube OD4mm ID2mm | 80mm | Filament input tube, recommended to get a continuous 1 meter lot for the project | [PTFE TUBES](https://www.aliexpress.com/item/1005008385732729.html) OR [PTFE TUBES](https://www.aliexpress.com/item/1005001408141263.html) |
| DU19 | Stepper motor NEMA17 L=38mm | 1 | Optimal L=38(40)mm can be longer but affects wiring length and units sideways stacking fitment | [NEMA17](https://www.aliexpress.com/item/1005008459399126.html) |
| DU20 | Micro switch D2F | 2 | | [MICRO SWITCH](https://www.aliexpress.com/item/1005007068972436.html)  |
| DU21 | Led SK6182 RGBW | 1 | | [LED](https://www.aliexpress.com/item/1005001971988539.html) |
| DU22 | JST PH2.0 3-m-pin housing | 3 | Connector housing for male pins, switches and led chain to drive unit | [JST PH2.0 HOUSING](https://www.aliexpress.com/item/4000769860242.html) |
| DU23 | JST PH2.0 4-m-pin housing | 1 | Connector housing for male pins, motor input to drive unit | [JST PH2.0 HOUSING](https://www.aliexpress.com/item/4000769860242.html) |
| DU24 | JST PH2.0 male pin | 13 | | [JST PH2.0 MALE PIN](https://www.aliexpress.com/item/1005001831974253.html) |
| DU25 | JST PH2.0 6-fm-pin housing  | 1 | Connector housing for 6 female pins, motor connector | [JST PH2.0 HOUSING](https://www.aliexpress.com/item/1005003164558805.html) |
| DU26 | JST PH2.0 female pin | 4 | | [JST PH2.0 FEMALE PIN](https://www.aliexpress.com/item/4000684959147.html) |
| DU27 | FEP wire UL1332 AWG26 | ≈2m | OD max 1.1mm to fit wire bundles to channels in 3d printed parts at some tight places | [UL1332 FEP WIRE](https://www.aliexpress.com/item/1005001980629942.html) |
| DU28 | Cable ties, small | 4 | 1.8mm tie width, 3.5mm eye width | [SMALL CABLE TIE](https://www.aliexpress.com/item/32405034226.html) |

<br/>
<br/>
<br/>
<br/>
<br/>

bom_spool_controller

## SPOOL CONTROLLER (4x for 4 spool changer)

| Image # | Item | Qty | Info | Used in prototype 2025 |
|:---:|:---|:---:|:---|:---|
| SC01 | FHCS M3x8 | 3 | | |
| SC02 | Bearing pin 3x12mm | 1 | Same size as for drive unit geartrain | [BEARING PIN](https://www.aliexpress.com/item/33005238671.html) |
| SC03 | PTFE tube OD6mm ID4mm | 2x20mm | Spool controller contact surfaces, recommended to get continuous min. 3 meter lot for the project | [PTFE TUBES](https://www.aliexpress.com/item/1005008385732729.html) OR [PTFE TUBES](https://www.aliexpress.com/item/1005001408141263.html) |

<br/>
<br/>
<br/>
<br/>
<br/>

bom_roller_tray_lidded

## ROLLER TRAY (4x for 4 spool changer)

| Image # | Item | Qty | Info | Used in prototype 2025 |
|:---:|:---|:---:|:---|:---|
| RT01 | Heat set insert M3xD5xL4 | 3 | Same as Voron BOM size | |
| RT02 | FHCS M3x8 | 3 | | |
| RT03 | Bicycle inner tube | 2x35mm | Optimal flat width ≈40-45mm to be stretched on a 32mm diameter roller (Tip: flip inside out to hide molding seams)| |

<br/>
<br/>
<br/>
<br/>
<br/>

bom_hub_buffer

## HUB/BUFFER

| Image # | Item | Qty | Info | Used in prototype 2025 |
|:---:|---|:---:|:---|:---|
| HB01 | Heat set insert M3xD5xL4 | 10 | Same as Voron BOM size | |
| HB02 | SHCS M3x6 | 2 | | |
| HB03 | SHCS M3x10 | 8 | | |
| HB04 | Self tapping M2x8 flat tip  | 8 | Alternatively normal M2x10 can be used here | [SELF TAPPING FLAT TIP](https://www.aliexpress.com/item/1005008143160245.html) |
| HB05 | Spring D6xL20xWD0.4 | 1 | Tension spring for buffer slide (Total length with eyelets 6+8+6=20mm) | [TENSION SPRING](https://www.aliexpress.com/item/1005007596268334.html) |
| HB06 | Tube collet 4mm | 1 | Buffer output | [TUBE COLLET 4mm](https://www.aliexpress.com/item/1005008047671379.html) |
| HB07 | Tube collet 6mm | 5 | Hub inputs and hub internal PTFE retainer | [TUBE COLLET 6mm](https://www.aliexpress.com/item/1005007086985966.html) |
| HB08 | PTFE tube OD6mm ID4mm | 55mm | Buffer slide inner guide tube, recommended to get continuous min. 3 meter lot for the project  | [PTFE TUBES](https://www.aliexpress.com/item/1005008385732729.html) OR [PTFE TUBES](https://www.aliexpress.com/item/1005001408141263.html) |
| HB09 | Ball bearing MR63zz | 1 | Used as trigger for hub filament presence switch | [BEARING MR63zz](https://www.aliexpress.com/item/1005006129544529.html) |
| HB10 | Micro switch D2F | 1 | Hub filament presence switch | [MICRO SWITCH](https://www.aliexpress.com/item/1005007068972436.html)  |
| HB11 | Micro switch D2F-L | 2 | Buffer compressed and expanded switches with lever | [MICRO SWITCH](https://www.aliexpress.com/item/1005007068972436.html)  |
| HB12 | JST PH2.0 4-m-pin housing | 1 | Connector housing for male pins | [JST PH2.0 HOUSING](https://www.aliexpress.com/item/4000769860242.html) |
| HB13 | JST PH2.0 male pin | 4 | | [JST PH2.0 MALE PIN](https://www.aliexpress.com/item/1005001831974253.html) |
| HB14 | FEP wire UL1332 AWG26 | ≈0.4m  | OD max 1.1mm to fit wire bundles to channels in 3d printed parts at some tight places | [UL1332 FEP WIRE](https://www.aliexpress.com/item/1005001980629942.html) |

<br/>
<br/>
<br/>
<br/>
<br/>

bom_controller_box

## CONTROL BOARD BOX

| Image # | Item | Qty | Info | Used in prototype 2025 |
|:---:|---|:---:|:---|:---|
| CB01 | Heat set insert M3xD5xL4 | 10 | Same as Voron BOM size | |
| CB02 | SHCS M3x6 | 6 | | |
| CB03 | SHCS M3x20 | 4 | | |
| CB04 | Self tapping screw M2x5 | 2 | Or cut longer screw to 5mm (<6mm) thread length, longer interferes the controller board | |
| CB05 | Control board | 1 | For 4 spool units changer: a board with 4 stepper drivers, minimum 11 switch inputs and rgb | BTT MMB V1 discontinued OR [BTT MMB V2](https://biqu.equipment/products/bigtreetech-mmb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) |

<br/>
<br/>
<br/>
<br/>
<br/>

## GENERAL ASSEMBLY

| Image # | Item | Qty | Info | Used in prototype 2025 |
|:---:|---|:---:|:---|:---|
| FR01 | Threaded rod M12 | 2 | M12x1.75 DIN975, length depends on the changer and printer setups. (or 1/2"-13 UNC) | |
| FR02 | Washer M12 | 4 | M12x24x2.5 DIN125 (or 1/2"-13 UNC) | |
| FR03 | Nut M12 | 4 | M12x1.75 DIN934 (or 1/2"-13 UNC) | |
| FR04 | PTFE tube OD6mm ID4mm | ≈2.2m  | From drive units to hub, recommended to get continuous min. 3 meter lot for the project | [PTFE TUBES](https://www.aliexpress.com/item/1005008385732729.html) OR [PTFE TUBES](https://www.aliexpress.com/item/1005001408141263.html) |

<br/>
<br/>
<br/>
<br/>
<br/>

## OBSERVATIONS AND REMARKS

Why M12 threaded rods?<br/>
The prototype was designed for a 600 mm wide printer, where the stiffness provided by M12 rods was found to be optimal.
For those using imperial measurements, alternative STLs are provided for the closest equivalent, 1/2"-13 UNC. If you want to use smaller diameter rods, modify the STEP files or print reduction bushings.
<br/>
<br/>

6/4mm diameter PTFE tube in stead of usual 4/2mm?<br/>
Found it superior when prototyping, more kink resistant when bending and filament flows nicer in it.
<br/>
<br/>

UL1332 AWG26 FEP -wires?<br/>
Has generally thinner insulation (AWG26 outer diameter is 1.1mm). There are some channels in 3d printed parts where thicker outer diameter causes troubles. Also fits nicely to JST-PH2.0 terminals when crimping. (And it's easier to solder for slow solderers like me, the insulation melts more slowly...)
<br/>
<br/>

No ball bearings for spool rollers?<br/>
Peg in a hole and some silicone grease seems otimal, some resistance is desired to stop spool spinning when it needs to stop. Large extruder gears and NEMA17 steppers provide plenty pulling force and BOM stays a bit shorter.

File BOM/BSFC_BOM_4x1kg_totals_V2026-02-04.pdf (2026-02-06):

### Busy Snail Filament Changer (BSFC) BOM V.2026-02-04 for 4x1kg spool units changer, totals

Item | Qty | Info | 2026-02 sample link
Heat set insert M3xD5xL4 | 68 | Same as Voron BOM size
Flat Head Cap Screw M3x6 | 4
Flat Head Cap Screw M3x8 | 24
Socket Head Cap Screw M3x6 | 8
Socket Head Cap Screw M3x10 | 8
Socket Head Cap Screw M3x14 | 4
Socket Head Cap Screw M3x20 | 16
Socket Head Cap Screw M3x25 | 4
Socket Head Cap Screw M3x30 | 12
Self tapping screw M2x5 | 6
Self tapping screw M2x8 flat tip | 36 | | SELF TAPPING FLAT TIP (https://www.aliexpress.com/item/1005008143160245.html)
Nut M12 | 4 | M12x1.75 DIN934 | NUT (https://www.mcmaster.com/90591A181/)
Washer M12 | 4 | M12x24x2.5 DIN125 | WASHER (https://www.mcmaster.com/91166A290/)
Threaded rod M12 | 2 | M12x1.75 DIN975, length depends on the changer and printer setups | THREADED ROD (https://www.mcmaster.com/99067A254/)
BMG 17 teeth extruder gear | 4 | Extruder drive gear with grub screw for 5mm stepper shaft | BMG-17 GEAR (https://www.aliexpress.com/item/32969501213.html)
Ball bearing MR63zz | 8+1 | Included 8 in 4x HGX-lite extruder part kits, 1 extra needed | HGX-LITE KIT (https://www.aliexpress.com/item/1005008082439342.html) / BEARING MR63zz (https://www.aliexpress.com/item/1005006129544529.html)
Thumb screw assy with spring | 4+4 | Included 4 in 4x HGX-lite extruder part kits, 4 extras needed | HGX-LITE KIT (https://www.aliexpress.com/item/1005008082439342.html) / THUMB SCREW ASSY (https://www.aliexpress.com/item/32947691813.html)
Large extruder gear | 8 | Included in 4x HGX-lite extruder part kits | HGX-LITE KIT (https://www.aliexpress.com/item/1005008082439342.html)
Needle bearing 3x5x6.5mm | 8 | Included in 4x HGX-lite extruder part kits | HGX-LITE KIT (https://www.aliexpress.com/item/1005008082439342.html)
Bearing pin 3x16mm | 8 | Included in 4x HGX-lite extruder part kits | HGX-LITE KIT (https://www.aliexpress.com/item/1005008082439342.html)
Bearing pin 3x12mm | 12 | | BEARING PIN (https://www.aliexpress.com/item/33005238671.html)
Tension spring D6xL20xWD0.4 | 1 | Tension spring for buffer slide (Total length with eyelets 6+8+6=20mm) | TENSION SPRING (https://www.aliexpress.com/item/1005007596268334.html)
PTFE tube OD4mm ID2mm | 1m | | PTFE TUBE (https://www.aliexpress.com/item/1005008385732729.html)
PTFE tube OD6mm ID4mm | 3m | 3 meter continuous lot | PTFE TUBE (https://www.aliexpress.com/item/1005008385732729.html)
Tube collet 4mm | 5 | | TUBE COLLET 4mm (https://www.aliexpress.com/item/1005008047671379.html)
Tube collet 6mm | 9 | | TUBE COLLET 6mm (https://www.aliexpress.com/item/1005007086985966.html)
Cable ties, small | 20 | 1.8mm tie width, 3.5mm eye width | SMALL CABLE TIE (https://www.aliexpress.com/item/32405034226.html)
Bicycle inner tube | ≈0.3m | Optimal flat width ≈40-45mm to be stretched on a 32mm diameter roller, 8x35mm pieces

1

Stepper motor NEMA17 L=38mm | 4 | Optimal L=38(40)mm can be longer but affects wiring length and units sideways stacking fitment | NEMA17 (https://www.aliexpress.com/item/1005008459399126.html)
Led SK6182 RGBW | 4 | | LED (https://www.aliexpress.com/item/1005001971988539.html)
Micro switch D2F | 9 | | MICRO SWITCH (https://www.aliexpress.com/item/1005006056197655.html)
Micro switch D2F-L | 2 | | MICRO SWITCH (https://www.aliexpress.com/item/1005006056197655.html)
JST PH2.0 3-m-pin housing | 12 | Switch and led inlet drive unit | JST PH2.0 HOUSING (https://www.aliexpress.com/item/4000769860242.html)
JST PH2.0 4-m-pin housing | 5 | Motor inlet drive unit (4) and hub/buffer (1) | JST PH2.0 HOUSING (https://www.aliexpress.com/item/4000769860242.html)
JST PH2.0 6-fm-pin housing | 4 | Stepper motor connector | JST PH2.0 HOUSING (https://www.aliexpress.com/item/1005003164558805.html)
JST PH2.0 3-fm-pin housing | 12 | Wirings on drive unit ends | JST PH2.0 HOUSING (https://www.aliexpress.com/item/1005003164558805.html)
JST PH2.0 4-fm-pin housing | 5 | Wirings on drive unit and hub/buffer ends | JST PH2.0 HOUSING (https://www.aliexpress.com/item/1005003164558805.html)
JST PH2.0 male pin | 56 | | JST PH2.0 MALE PIN (https://www.aliexpress.com/item/1005001831974253.html)
JST PH2.0 female pin | 72 | | JST PH2.0 FEMALE PIN (https://www.aliexpress.com/item/4000684959147.html)
FEP wire UL1332 26AWG | ≈25m | OD max 1.1mm to fit wire bundles to channels in 3d printed parts at some tight places | UL1332 FEP WIRE (https://www.aliexpress.com/item/1005001980629942.html)
Control board* | 1 | For 4 spool units changer: a board with 4 stepper drivers, minimum 11 switch inputs and rgb | BTT MMB CAN V2 (https://biqu.equipment/products/bigtreetech-mmb)

*Control board box and wiring instructions supports Btt Mmb Can V1 and V2 boards. Wiring connectors on board end are not included in this BOM.

Item | Qty | Info | 2026-02 sample link

2

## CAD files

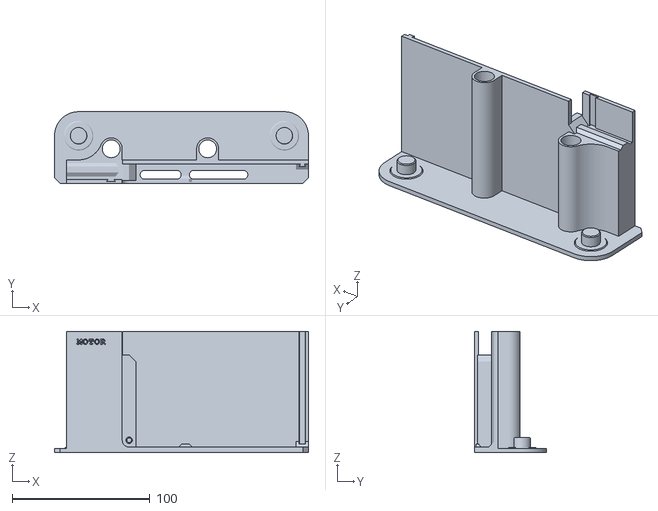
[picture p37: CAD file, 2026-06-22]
MODs/_BUSY_SNAIL_DESIGN_LAB/5KG_ESUN/STLs/0.5-13_UNC/BSFC_RT_5kg_W175xD300_tray_main_left_0.5-13_UNC.stl
184.3 x 52.0 x 88.0

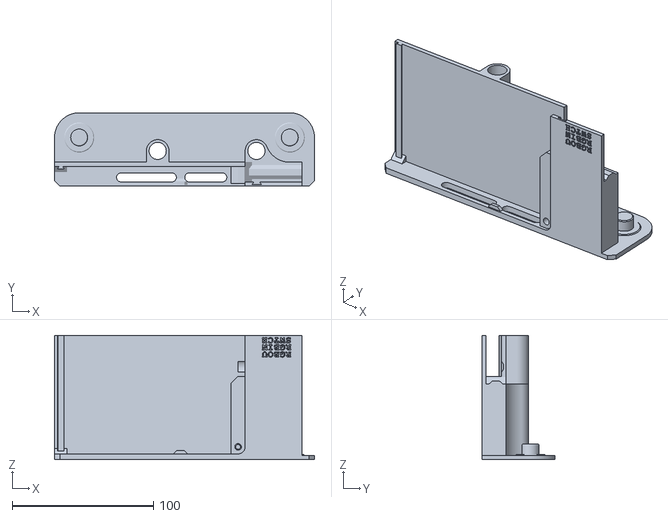
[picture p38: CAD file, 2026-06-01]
MODs/_BUSY_SNAIL_DESIGN_LAB/5KG_ESUN/STLs/BSFC_RT_5kg_W176xD300_tray_main_right.stl
184.3 x 52.0 x 88.0

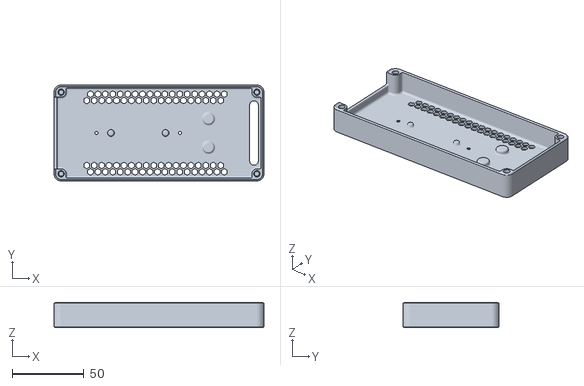
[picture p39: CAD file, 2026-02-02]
STLs/CONTROLLER_BOX/BSFC_CB_main.stl
146.8 x 67.0 x 17.5

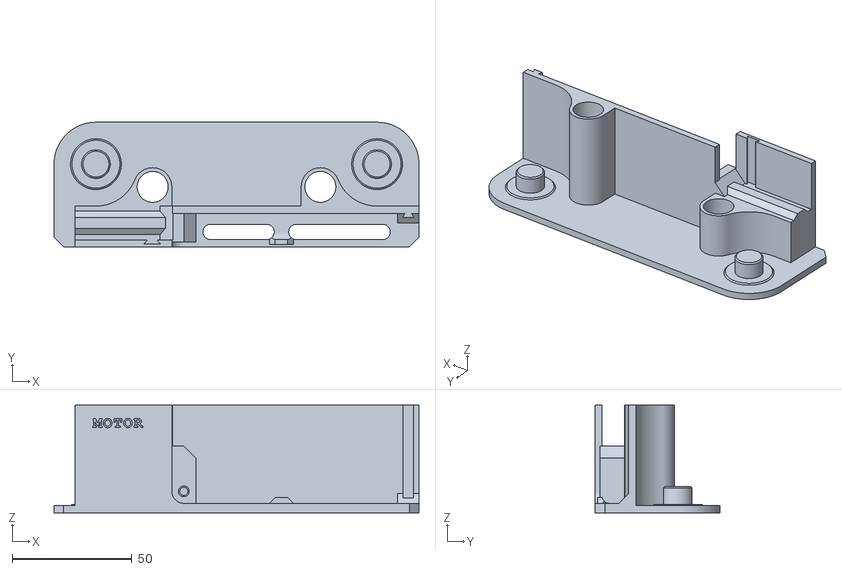
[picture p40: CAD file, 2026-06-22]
STLs/ROLLER_TRAY/0.5-13_UNC/BSFC_RT_1kg_W90_tray_main_left_0.5-13_UNC.stl
152.3 x 52.0 x 45.0

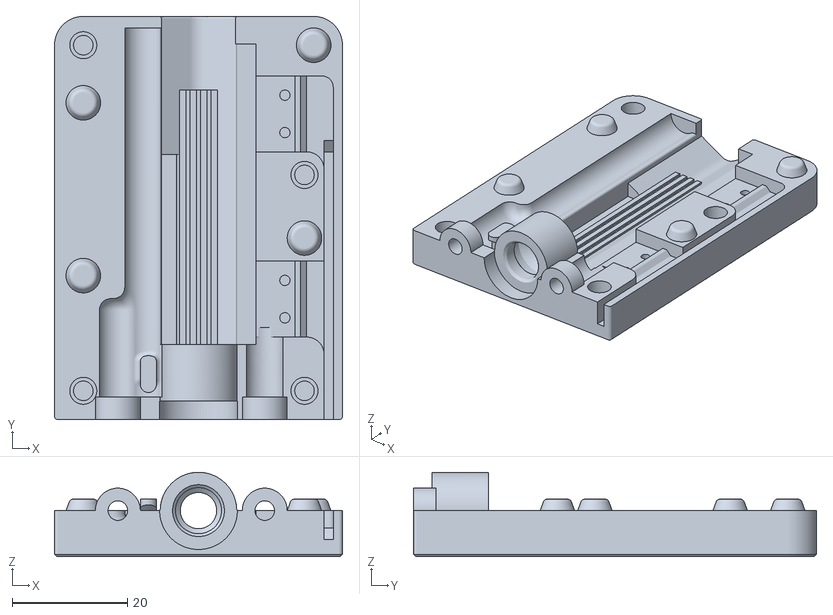
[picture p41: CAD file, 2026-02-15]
STLs/HUB_BUFFER/BSFC_HB_buffer_main.stl
50.0 x 70.0 x 14.6

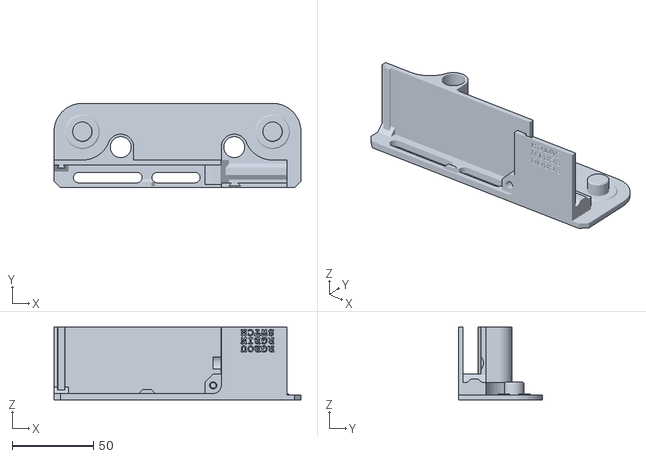
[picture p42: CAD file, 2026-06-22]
STLs/ROLLER_TRAY/0.5-13_UNC/BSFC_RT_1kg_W90_tray_main_right_0.5-13_UNC.stl
152.3 x 52.0 x 45.0

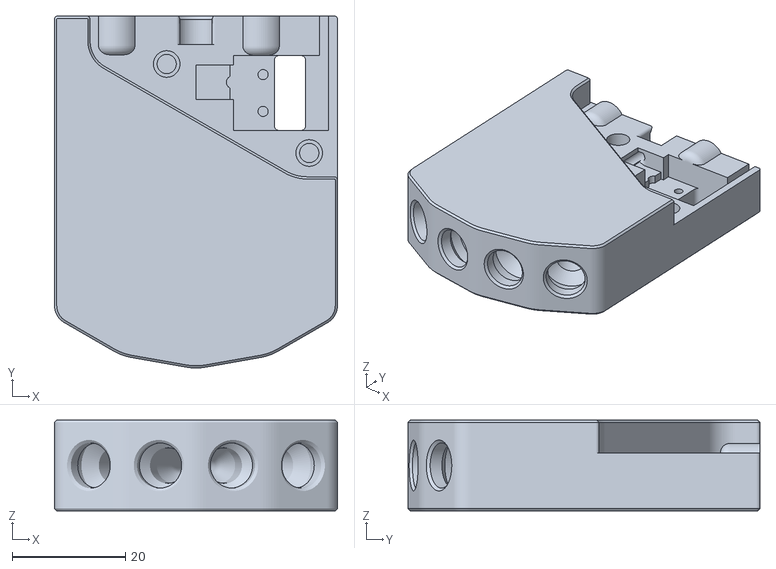
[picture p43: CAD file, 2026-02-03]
STLs/HUB_BUFFER/BSFC_HB_hub_main.stl
50.0 x 62.2 x 16.0

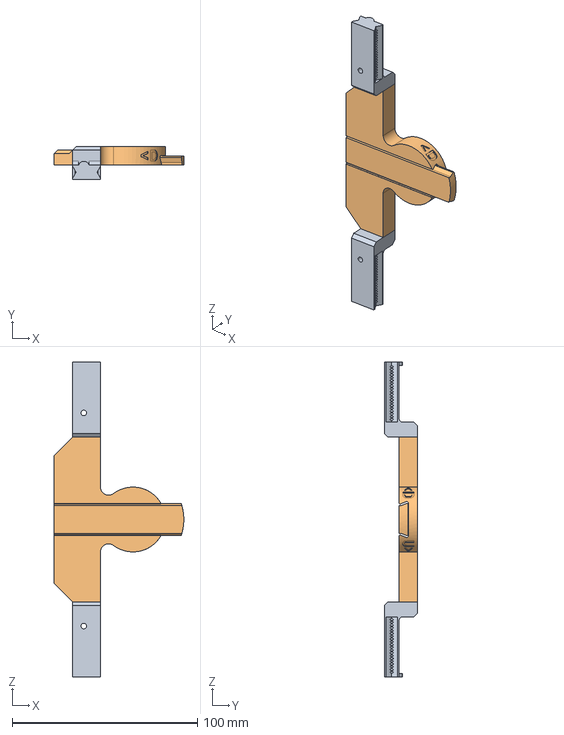
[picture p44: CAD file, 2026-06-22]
MODs/_BUSY_SNAIL_DESIGN_LAB/5KG_ESUN/STEPs/BSFC_SC_slide_5kg_W170.step
70.0 x 18.0 x 170.0 mm

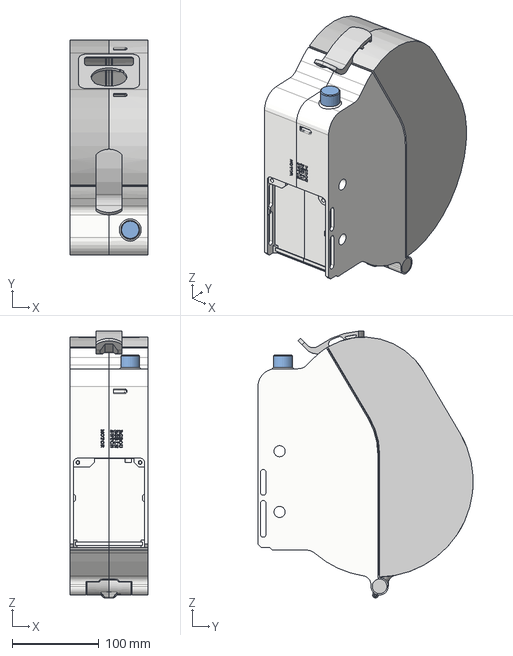
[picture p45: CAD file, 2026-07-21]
MODs/_BUSY_SNAIL_DESIGN_LAB/DRY_BOX/STEPs/BSFC_Dry_Box.step
90.0 x 248.2 x 307.9 mm

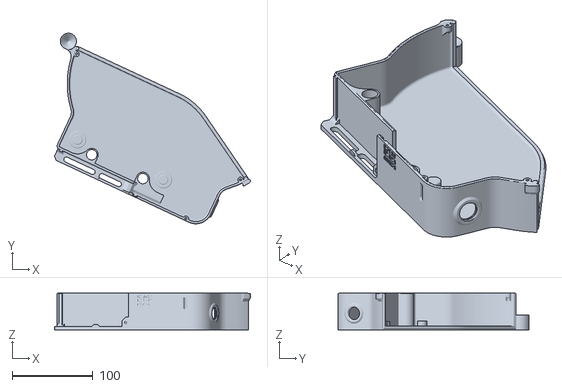
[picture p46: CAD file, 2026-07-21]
MODs/_BUSY_SNAIL_DESIGN_LAB/DRY_BOX/STLs/0.5-13_UNC/BSFC_DB_1kg_W90_box_right_0.5-13_UNC.stl
243.1 x 236.5 x 45.6

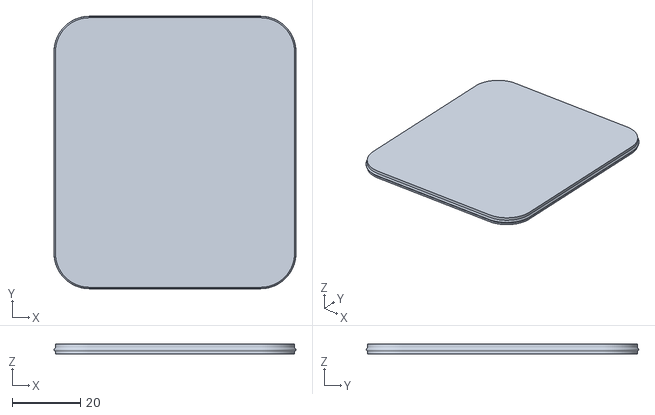
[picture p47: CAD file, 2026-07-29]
MODs/_BUSY_SNAIL_DESIGN_LAB/DRY_BOX/STLs/BSFC_DB_lid_plate_solid.stl
70.8 x 79.7 x 2.80

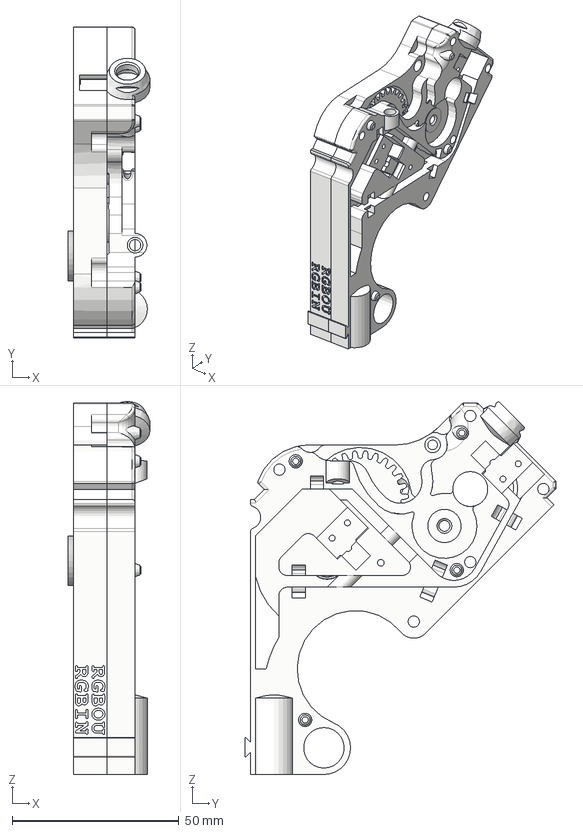
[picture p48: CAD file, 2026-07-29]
MODs/_BUSY_SNAIL_DESIGN_LAB/GEAR_TRAIN_BALL_BEARING/STEPs/BSFC_DU_BBgeartrain.step
24.5 x 93.4 x 111.9 mm
DriveUnit
RewindGears
Bearing_MR117zz
Bearing_F6700zz
Bearing_MR63zz x 4

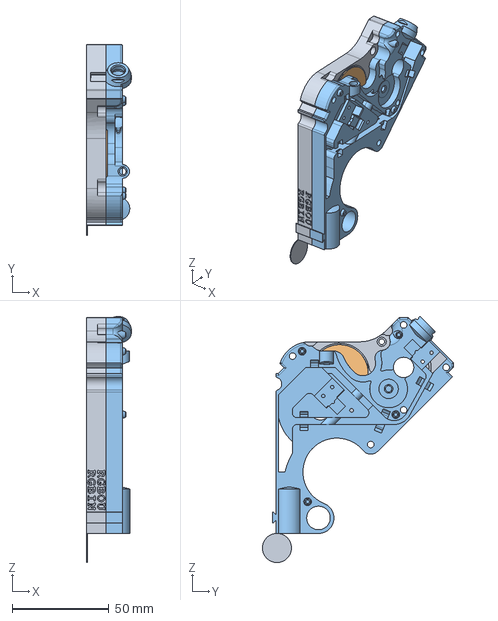
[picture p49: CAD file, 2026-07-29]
MODs/_BUSY_SNAIL_DESIGN_LAB/GEAR_TRAIN_BALL_BEARING/STEPs/ITEMS_WITH_PRINTING_HELPERS/BSFC_DU_BBgeartrain_onlyblocks.step
22.9 x 98.6 x 126.8 mm

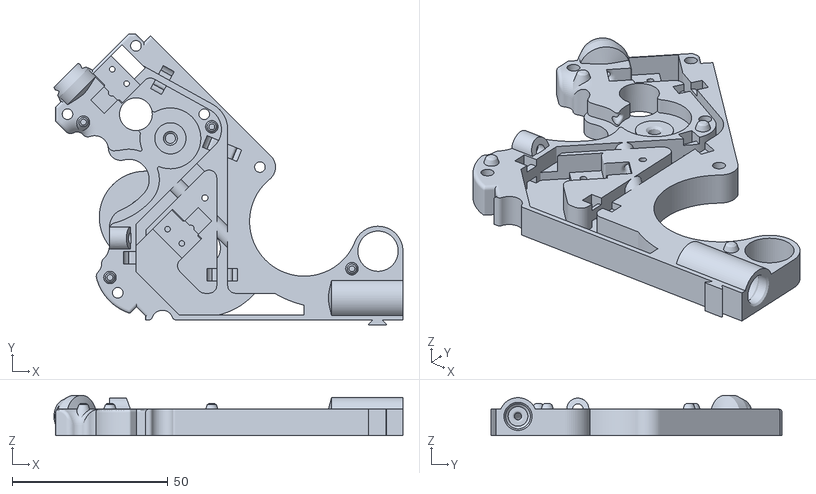
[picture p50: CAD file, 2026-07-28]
MODs/_BUSY_SNAIL_DESIGN_LAB/GEAR_TRAIN_BALL_BEARING/STLs/0.5-13_UNC/BSFC_MOD_DU_BB_block_extruder_0.5-13_UNC.stl
111.9 x 93.4 x 12.9

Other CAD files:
STLs/ROLLER_TRAY/BSFC_RT_1kg_W90_tray_main_left.stl
MODs/_BUSY_SNAIL_DESIGN_LAB/5KG_ESUN/STLs/0.5-13_UNC/BSFC_RT_5kg_W175xD300_tray_main_right_0.5-13_UNC.stl
MODs/_BUSY_SNAIL_DESIGN_LAB/5KG_ESUN/STLs/BSFC_RT_5kg_W176xD300_tray_main_left.stl
STLs/ROLLER_TRAY/BSFC_RT_1kg_W90_tray_main_right.stl
MODs/_BUSY_SNAIL_DESIGN_LAB/5KG_ESUN/STLs/BSFC_RT_5kg_W176_roller_front.stl
MODs/_BUSY_SNAIL_DESIGN_LAB/5KG_ESUN/STLs/BSFC_RT_5kg_W176_roller_rear.stl
MODs/_BUSY_SNAIL_DESIGN_LAB/5KG_ESUN/STLs/BSFC_RT_5kg_W176_tray_lid_bottom.stl
MODs/_BUSY_SNAIL_DESIGN_LAB/5KG_ESUN/STLs/BSFC_RT_5kg_W176_tray_skirt_rear.stl
MODs/_BUSY_SNAIL_DESIGN_LAB/5KG_ESUN/STLs/BSFC_SC_slide_5kg_W170.stl
MODs/_BUSY_SNAIL_DESIGN_LAB/DRY_BOX/STLs/0.5-13_UNC/BSFC_DB_1kg_W90_box_left_0.5-13_UNC.stl
MODs/_BUSY_SNAIL_DESIGN_LAB/DRY_BOX/STLs/BSFC_DB_1kg_W90_box_left.stl
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

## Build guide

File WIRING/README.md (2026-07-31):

# Busy Snail Filament Changer (BSFC) Wiring

These wiring instructions currently support two control boards: Bigtreetech MMB CAN V1.1 and V2. The internal wiring of the drive units and hub/buffer is universal. The LED, stepper motor, and hub/buffer intermediate wiring is the same for both boards. However, the wiring between the filament switches of the drive unit and the control board is board-specific.

For the internal wiring of the drive unit and the hub/buffer, it is recommended to use UL1332 AWG26 FEP wire (with an outer diameter of 1.1 mm) because the 3D-printed components have tight spots in their wire channels. The insulation thickness and outer diameter of PVC-insulated wire are usually larger, which may cause installation challenges.

There is no issue with using thicker wire for the connections between the control board, the drive unit, and the hub/buffer. For the stepper motor wiring, a typical ribbon cable is a good choice to keep the bundles neater.

<br/>

## Wiring Diagrams

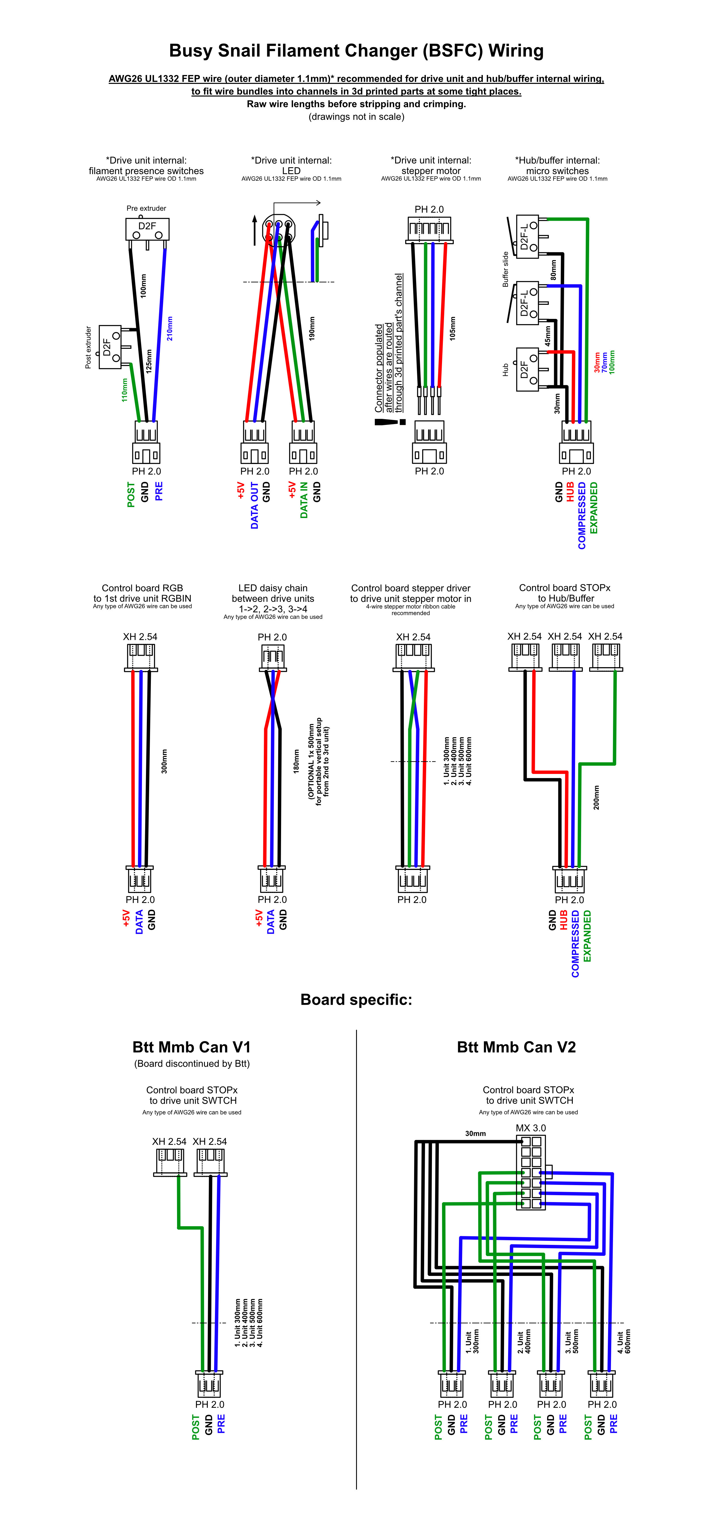
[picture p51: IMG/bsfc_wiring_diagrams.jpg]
bsfc_wiring_diagrams


<br/>

## Control Board Connections

<details>
<summary>Control Board Connections and Corresponding Pin Mappings for AFC-Klipper-Add-On</summary>

## Bigtreetech mmb can v1.1
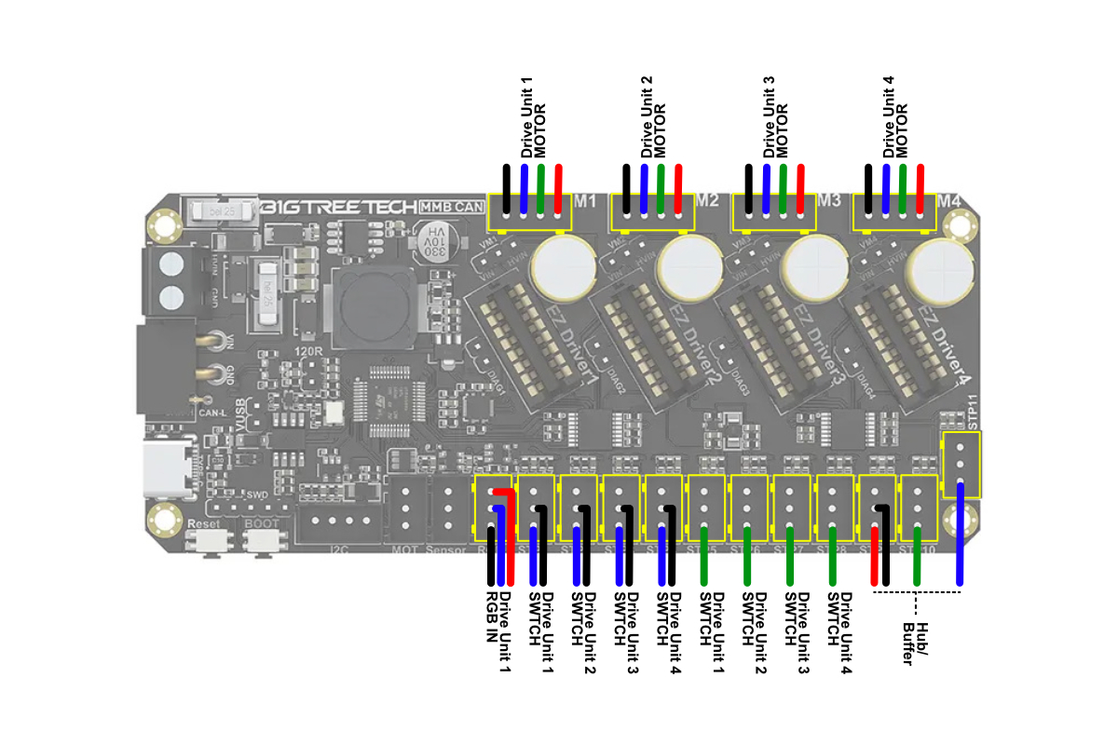
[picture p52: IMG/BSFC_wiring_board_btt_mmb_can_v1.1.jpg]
BSFC_wiring_board_btt_mmb_can_v1.1


Pin mappings for Bigtreetech mmb can v1.1 control board:

/config/AFC/mcu/MMB_1.1.cfg

```
[board_pins Your_Unit_Name]
mcu: Your_Mcu_Name
aliases:
    M1_STEP=PB15   , M1_DIR=PB14   , M1_EN=PB8    , M1_UART=PA10   ,
    M2_STEP=PD2    , M2_DIR=PB13   , M2_EN=PD1    , M2_UART=PC7    ,
    M3_STEP=PD0    , M3_DIR=PD3    , M3_EN=PA15   , M3_UART=PC6    ,
    M4_STEP=PB6    , M4_DIR=PB7    , M4_EN=PB5    , M4_UART=PA9    ,

	HUB=PB11 		, 
	TRG1=PA3  		, TRG2=PA4  	, TRG3=PB9 		, TRG4=PA8		,
	EXT1=PC15 		, EXT2=PC13		, EXT3=PC14		, EXT4=PB12		,
    TN_ADV=PB10     , TN_TRL=PB2 ,
	RGB1=PA2		, 
```

<br/>
<br/>

## Bigtreetech mmb can v2.0
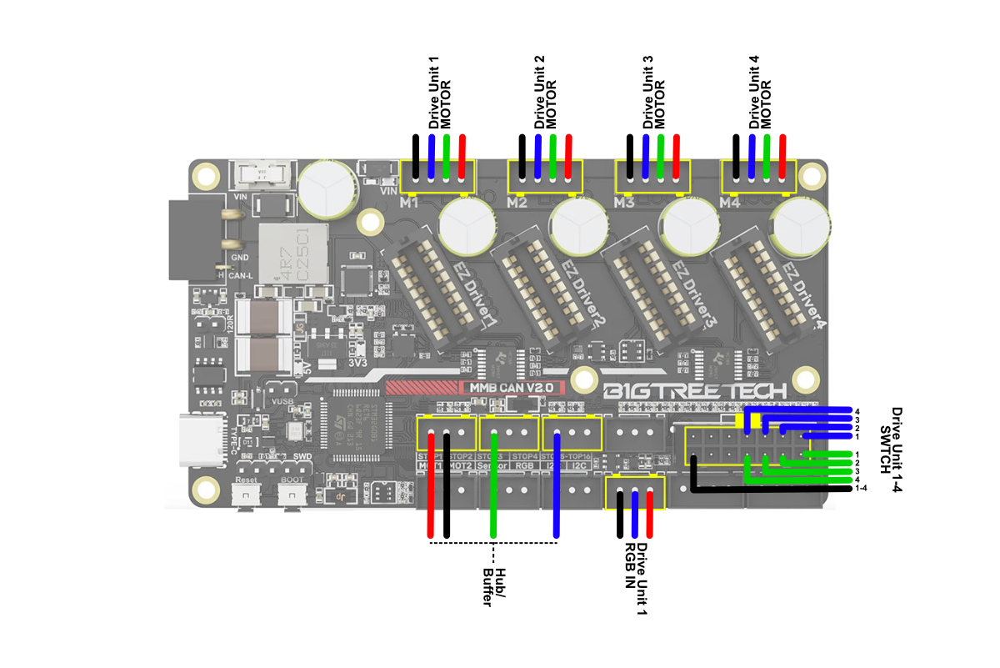
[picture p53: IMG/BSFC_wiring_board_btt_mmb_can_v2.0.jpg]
BSFC_wiring_board_btt_mmb_can_v2.0


Pin mappings for Bigtreetech mmb can v2.0 control board:

/config/AFC/mcu/MMB_2.0.cfg

```
[board_pins Your_Unit_Name]
mcu: Your_Mcu_Name
aliases:
    M1_STEP=PD4    , M1_DIR=PD3    , M1_EN=PD5    , M1_UART=PB5    ,
    M2_STEP=PC9    , M2_DIR=PC8    , M2_EN=PD2    , M2_UART=PB4    ,
    M3_STEP=PC15   , M3_DIR=PC11   , M3_EN=PC10   , M3_UART=PB3    ,
    M4_STEP=PC13   , M4_DIR=PC12   , M4_EN=PC14   , M4_UART=PD6    ,

	HUB=PA15 		, 
	TRG1=PC5  		, TRG2=PB1  	, TRG3=PB10		, TRG4=PB12 	,
	EXT1=PC4  		, EXT2=PB0 		, EXT3=PB2 		, EXT4=PB11		,
    TN_ADV=PA10     , TN_TRL=PD9 ,
	RGB1=PC3		, 
```

</details>

<br/>

## Sample Pictures of Prototype Wire Assemblies

Some example pictures from the prototype phase showing soldered and crimped wire assemblies. The pictures are presented in the same order as they appear in the wiring diagram above.

<details>
<summary>Prototype Wire Assemblies</summary>
	
<br/>

Drive unit internal: filament presence switches
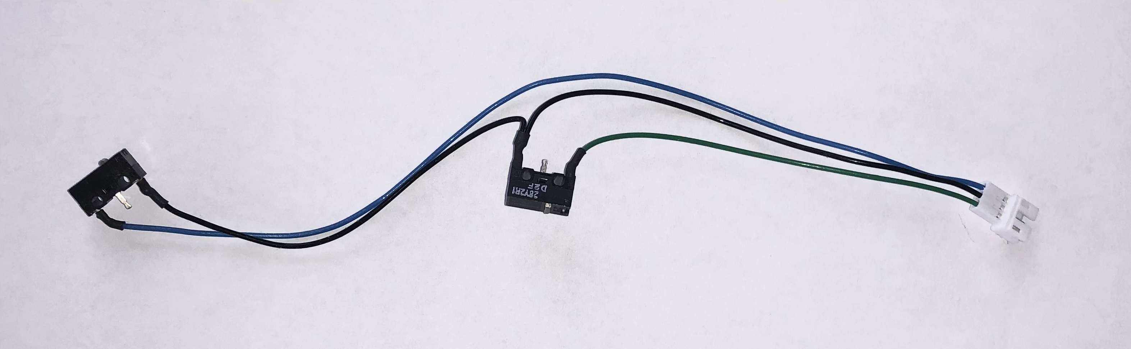
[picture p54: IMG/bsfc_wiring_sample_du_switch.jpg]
bsfc_wiring_sample_du_switch


Drive unit internal: LED
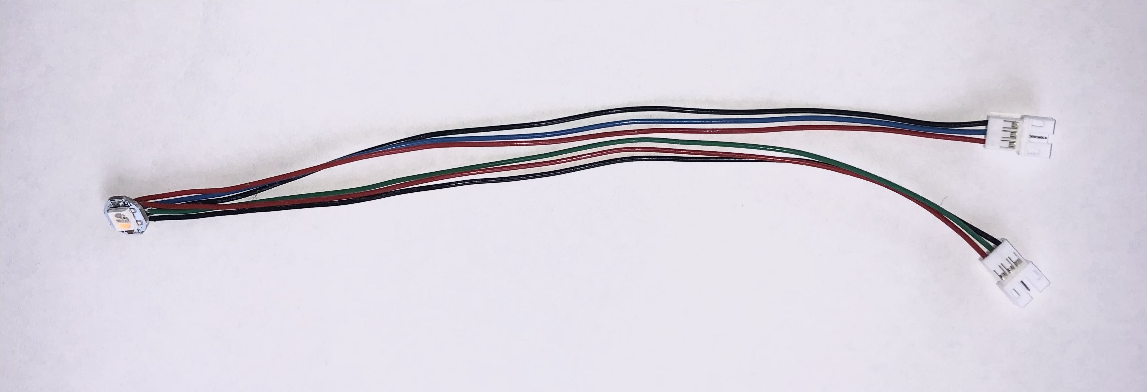
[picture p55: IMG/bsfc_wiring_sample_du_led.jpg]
bsfc_wiring_sample_du_led


Drive unit internal: stepper motor <br/>
(JST PH2.0-4 connector populated after wires are routed through 3d printed part's channel)
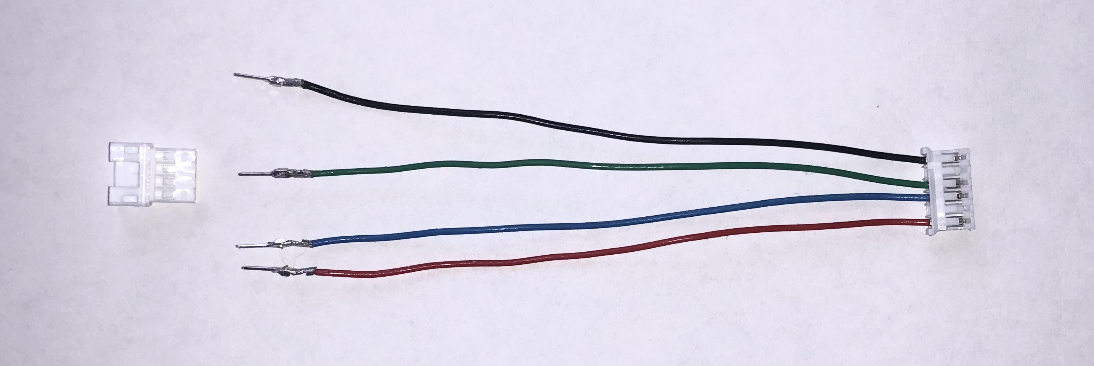
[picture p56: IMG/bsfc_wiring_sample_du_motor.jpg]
bsfc_wiring_sample_du_motor


Hub/buffer internal: micro switches
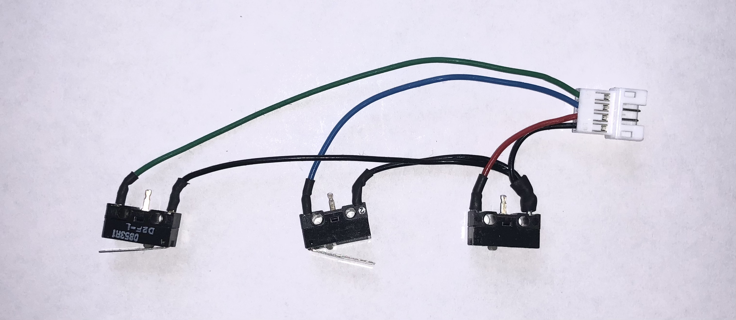
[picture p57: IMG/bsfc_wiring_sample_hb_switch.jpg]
bsfc_wiring_sample_hb_switch


Control board RGB to 1st drive unit RGBIN
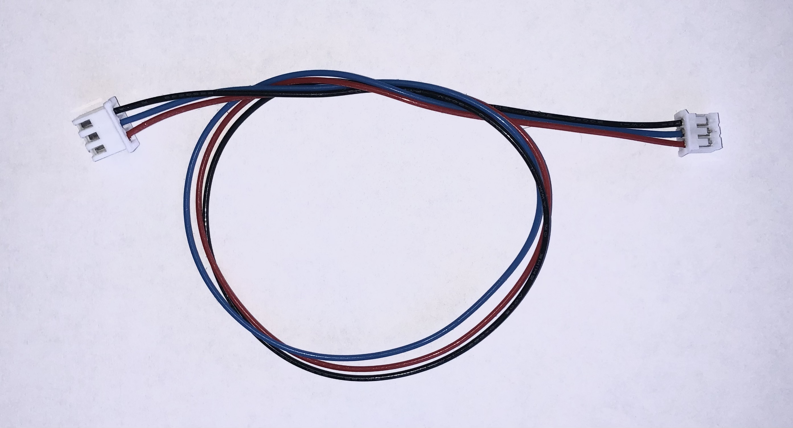
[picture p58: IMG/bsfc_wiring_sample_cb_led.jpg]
bsfc_wiring_sample_cb_led


LED daisy chain between drive units 1->2, 2->3, 3->4 (RGBOU -> RGBIN)
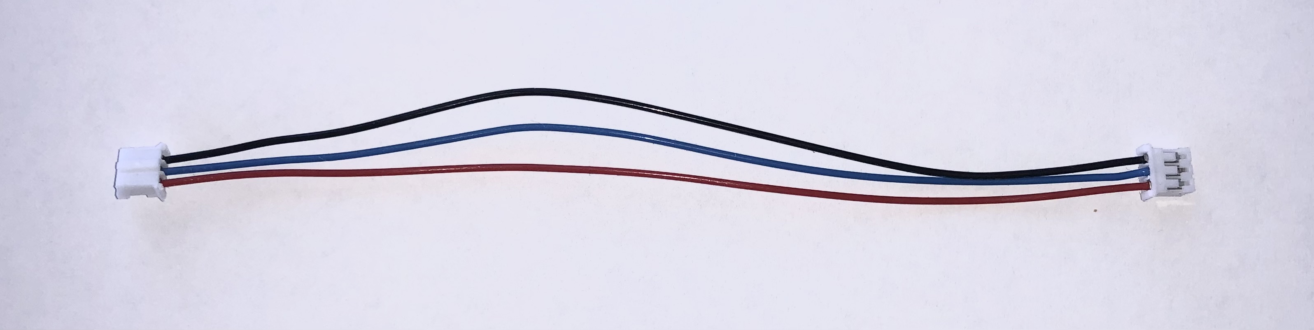
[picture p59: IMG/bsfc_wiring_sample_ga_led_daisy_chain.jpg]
bsfc_wiring_sample_ga_led_daisy_chain


Control board stepper driver to drive unit stepper MOTOR in (Sample: 1st unit 300mm)
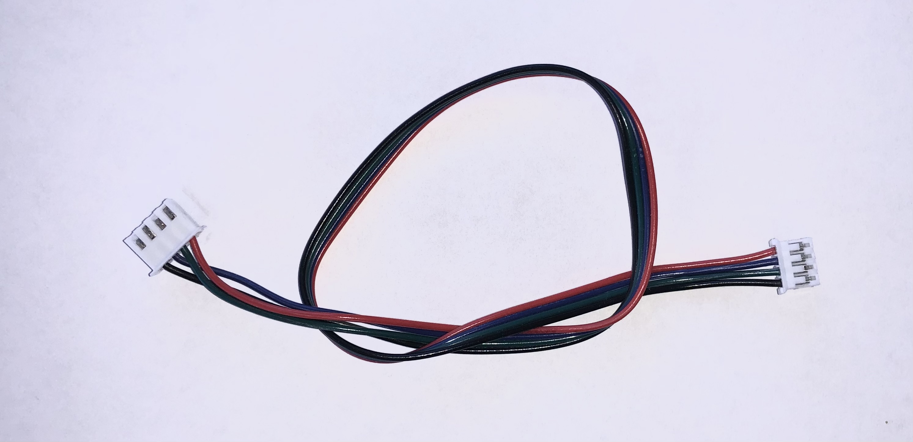
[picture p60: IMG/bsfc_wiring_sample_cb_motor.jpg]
bsfc_wiring_sample_cb_motor


Control board STOPx to Hub/Buffer
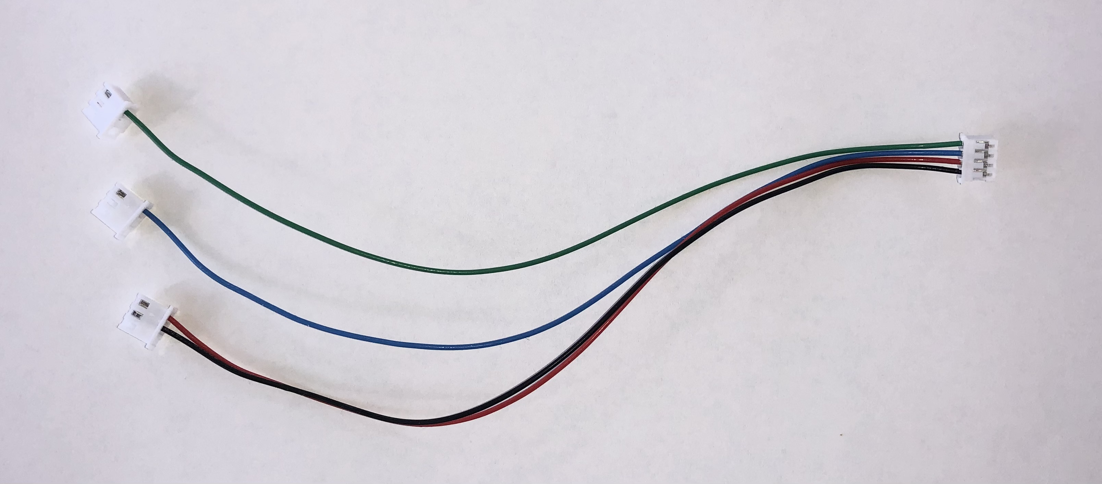
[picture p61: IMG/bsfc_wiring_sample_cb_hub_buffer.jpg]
bsfc_wiring_sample_cb_hub_buffer


Control board STOPx to drive unit SWTCH (Sample: Btt Mmb Can V2)
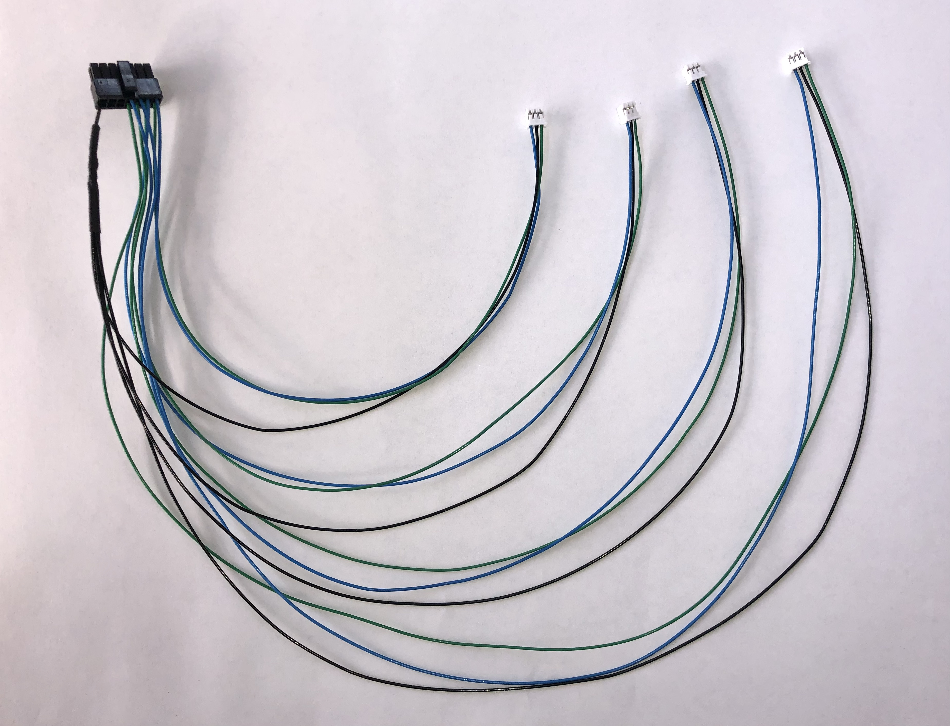
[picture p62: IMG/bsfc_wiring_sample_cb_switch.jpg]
bsfc_wiring_sample_cb_switch


</details>

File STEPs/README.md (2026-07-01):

# Busy Snail Filament Changer (BSFC) STEPs

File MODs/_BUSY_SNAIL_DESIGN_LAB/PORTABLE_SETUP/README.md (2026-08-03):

# Busy Snail Filament Changer (BSFC) <ins> Portable Setup Mod </ins> by Busy Snail Design Lab

## Additional BOM

| Item | Qty | Info | Used in prototype 2025 |
|:---|:---:|---|:---|
| SHCS M3x8 | 2 | | |
| SHCS M3x16 | 2 | | |
| Washer M12 | 4 | M12x24x2.5 DIN125 (or 1/2"-13 UNC) | |
| Nut M12 | 4 | M12x1.75 DIN934 (or 1/2"-13 UNC) | |

(https://youtu.be/CcmCndIJ5CE)
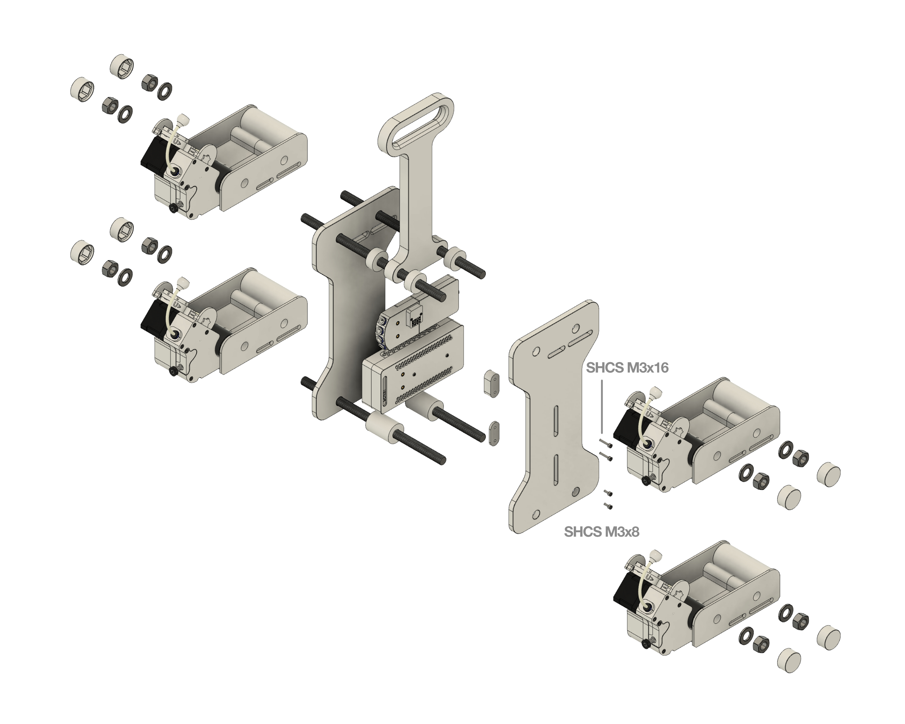
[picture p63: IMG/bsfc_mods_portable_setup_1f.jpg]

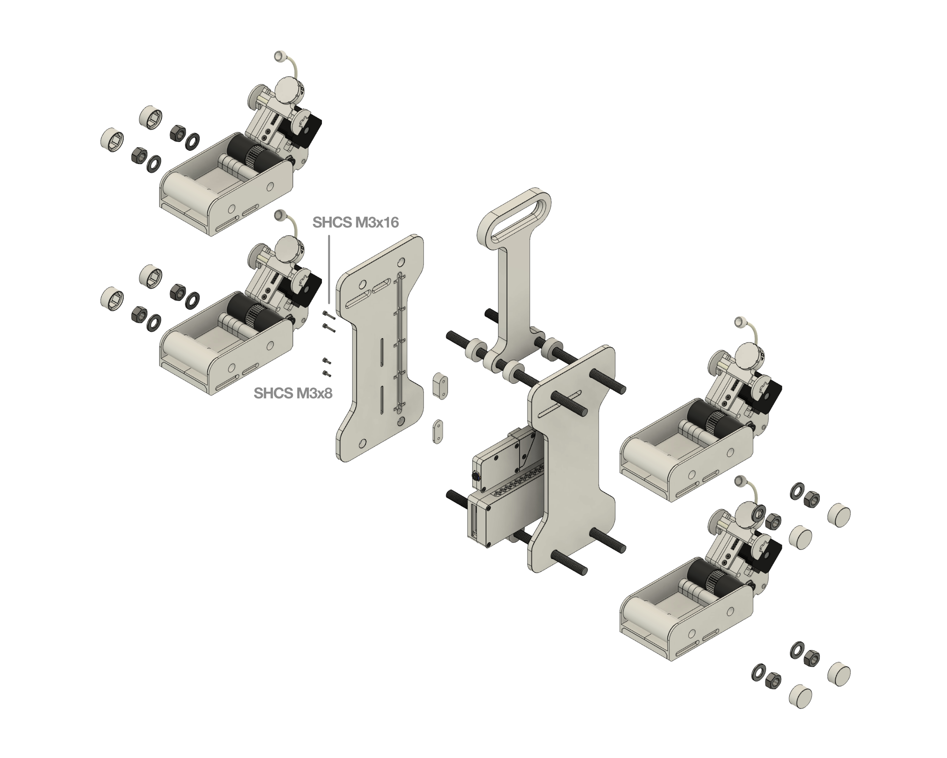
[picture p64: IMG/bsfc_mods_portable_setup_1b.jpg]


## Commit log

2026-01-09 Create STL
2026-01-09 Create BOM
2026-01-09 Update BOM
2026-01-13 Create WIRING
2026-01-20 Controller box stls
    [BSFC_CB_board_bracket_BTT-MMB-CAN-V1.stl, BSFC_CB_board_bracket_BTT-MMB-CAN-V2.stl, BSFC_CB_grill_x2.stl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]
2026-01-22 Add step-files
    [BSFC_Buffer.step, BSFC_Controller_Box_Btt_Mmb_V1-2.step, BSFC_Hub.step]
2026-01-24 Update BSFC_DU_led_diffuser.stl
    Increased clearance
    [BSFC_DU_led_diffuser.stl]
2026-01-24 Update BSFC_RT_1kg_W90_roller_front.stl
    Increased clearances
    [BSFC_RT_1kg_W90_roller_front.stl]
2026-01-24 Update BSFC_RT_1kg_W90_roller_rear.stl
    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
    [BSFC_RT_1kg_W90_roller_rear.stl]
2026-01-24 Update BSFC_RT_1kg_W90_tray_rear_beam.stl
    Bottom lid mod
    [BSFC_RT_1kg_W90_tray_rear_beam.stl]
2026-01-24 Update BSFC_RT_1kg_W90_tray_left.stl
    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
    [BSFC_RT_1kg_W90_tray_left.stl]
2026-01-24 Update BSFC_RT_1kg_W90_tray_right.stl
    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
    [BSFC_RT_1kg_W90_tray_right.stl]
2026-01-26 Clean up dir-file structure
    [BSFC_DU_block_clutch.stl, BSFC_DU_block_extruder.stl, BSFC_DU_block_motor.stl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]
2026-01-28 Spool controller rail holes adjusted
    [BSFC_DU_block_clutch.stl]
2026-01-28 Spool controller new spin-to-adjust -version
    [BSFC_SC_rail.stl, BSFC_SC_slide_1kg_W80.stl, BSFC_SC_slider_80_universal.stl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]
2026-01-29 Spool controller tweaks
    [BSFC_SC_end_guides.stl, BSFC_SC_slide_1kg_W80.stl]
2026-01-30 Spool controller slide, rail and thumb wheel tweaks
    [BSFC_SC_slide_1kg_W80.stl]
2026-02-02 Added align features to box and board brackets
    [BSFC_CB_board_bracket_BTT-MMB-CAN-V1.stl, BSFC_CB_board_bracket_BTT-MMB-CAN-V2.stl, BSFC_CB_main.stl]
2026-02-03 Hub ptfe collet hole tweak
    [BSFC_HB_hub_main.stl]
2026-02-03 Drive unit ptfe outlet collet hole tweak
    [BSFC_DU_block_extruder.stl]
2026-02-04 BOM totals pdf update
2026-02-09 Rgb in and out texts swapped
    [BSFC_DU_block_motor.stl, BSFC_RT_1kg_W90_tray_main_right.stl]
2026-02-09 Alignment edges for microswitches added
    [BSFC_HB_buffer_main.stl]
2026-02-15 Wiring channel edge fillet
    [BSFC_HB_buffer_main.stl]
2026-02-15 Missing spring hook added
    [BSFC_HB_buffer_slide_outlet4mm.stl]
2026-02-18 Minor tweak for jst connector seating
    [BSFC_DU_block_clutch.stl]
2026-02-18 Gear pins interface tweak
    [BSFC_DU_block_motor.stl]
2026-02-19 Tools added to STLs
    [BSFC_TL_clutch_punch.stl, BSFC_TL_gear_pin_gluing_jig.stl, BSFC_TL_wire_puller_jst_ph_m3pin.stl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]
2026-02-21 Drive unit LED and SWITCH wiring a bit longer
2026-02-23 Drive unit LED and SWITCH wire length tweaks
2026-02-23 Rewind gears 2nd and 3rd center hole larger clearance
    [BSFC_DU_rewind_geartrain.stl]
2026-02-24 Drive unit SWITCH wire length tweaks
2026-03-23 Led daisy chain wires between drive units 30mm longer, 150 to 180mm, considering portable vertical setup
2026-05-24 More STLs
    [BSFC_DU_led_diffuser_0.stl, BSFC_DU_led_diffuser_1.stl, BSFC_DU_led_diffuser_2.stl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]
2026-05-26 Unifying tweaks that account for the optional ball bearing rewind geartrain mod
    [BSFC_DU_block_extruder.stl, BSFC_DU_block_motor.stl, BSFC_DU_block_outer.stl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]
2026-06-06 Add some wiring sample images
2026-06-22 Add STLs to support 1/2-13 UNC threaded rods
    [BSFC_DU_block_clutch_0.5-13_UNC.stl, BSFC_DU_block_extruder_0.5-13_UNC.stl, BSFC_DU_block_motor_0.5-13_UNC.stl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]
2026-06-22 STEPs added
    [BSFC_Buffer.step, BSFC_Controller_Box_Btt_Mmb_V1-2.step, BSFC_Hub.step]
2026-06-22 More STEPs
    [BSFC_DU_blocks.step, BSFC_DU_filament_inlet_cone.step, BSFC_DU_rewind_clutch.step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]
2026-07-21 Dry box proto added
    [BSFC_DB_1kg_W90_box_left.stl, BSFC_DB_1kg_W90_box_left_0.5-13_UNC.stl, BSFC_DB_1kg_W90_box_right.stl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]
2026-07-27 Add control board images
2026-07-29 Add portable setup MOD
    [BSFC_MOD_PORTABLE_carry_handle.stl, BSFC_MOD_PORTABLE_carry_handle_0.5-13_UNC.stl, BSFC_MOD_PORTABLE_frame_left.stl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]
2026-08-03 Update README with additional BOM items
    Added additional items to the BOM with details.
2026-08-03 Clarify Busy Snail Filament Changer description
    Updated the description of the Busy Snail Filament Changer to clarify its functionality.
2026-08-03 Revise description of Busy Snail Filament Changer
